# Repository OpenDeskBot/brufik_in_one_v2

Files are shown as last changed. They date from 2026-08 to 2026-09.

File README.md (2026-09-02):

# Brufik in One — 一个住在你桌面的硅基朋友

你好！这里有一个**硅基朋友**，你想认识一下吗？

他会睁大眼睛看着你说话，被夸奖时害羞脸红、眨眼睛，被吵醒时一脸迷糊；他记得你说过的话——知道你喜欢喝咖啡，下午 3 点会主动提醒你「该站起来活动啦」；你问他天气，他真的会去网上查，查完还得意地晃两下脑袋；你打断他说话，他会乖乖停下来听你说。

他不是视频里的 demo，而是**开源、可以亲手攒出来**的：3D 打印外壳 + ESP32 主控 + 一块小屏幕 + 两个舵机 + 一个喇叭，配上一套全开源的语音 AI 后台，百元级预算就能从零到「活」。

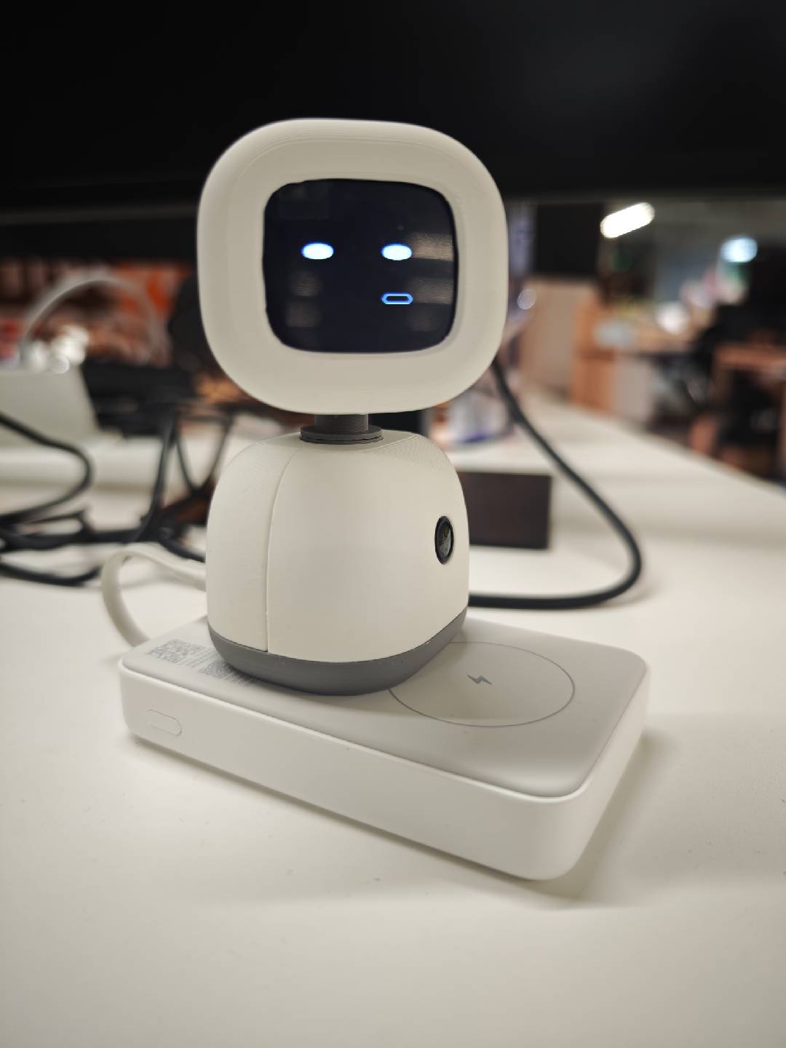
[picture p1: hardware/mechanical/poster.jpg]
Brufik 桌面机器人实物


---

## 为什么值得一试

- 🗣️ **开口即聊，无唤醒词**：插电上电，直接对它说话。VAD 自动起停，不用按键、不用喊「你好小歪」。
- 😊 **表情 + 音素级口型**：TTS 返回音素时间戳，屏幕上的嘴型逐帧对齐声音；语音、嘴型、底部屏显文字三路同步。
- 🎙️ **全双工音频（AEC）**：它说话时你可以直接打断——回声消除（ESP-SR AFE）让它「边听边说」，而不是死板地你一句我一句排队。
- ⚡ **随时打断**：高优先级消息（如闹钟、紧急提醒）通过 `pb_cancel` 抢占，立刻打断低优先级播放。
- 👀 **认人 + 追视**：认得的脸能叫出名字（MediaPipe 检测 + InsightFace 512 维档案），摄像头自动转头跟随。
- 🌐 **LLM 工具生态**：联网搜索、抓网页、拍照取景、登记人脸、读写文件沙箱……LLM 不只聊天，还能动手。
- 📦 **全栈开源**：STEP 结构件、PCB、自定义 bootloader、ESP32 固件、Python 后台、Web 控制台，一套仓库交付，可完整复刻。

---

## 它怎么「活」起来

设备端「轻」、后台端「重」：ESP32 只负责采音、播音、画屏、转舵机；所有智能（识别、对话、人脸、记忆、定时）都在后台。两者通过**一条 WebSocket 长连接**（`/asr_chat`）实时联动。

```
你说话 → 设备采集 PDM 麦克风（16kHz）
              │  audio 帧上行（Opus/PCM + flush）
              ▼
        服务端语音管线：VAD → ASR → LLM(工具) → TTS → 组帧
              │  pb_start / pb_chunk / pb_end + 24kHz PCM 下行
              ▼
        设备端回应：播音 + 嘴型 + 转头 + 屏显文字 + RGB 状态灯
```

> 详细协议见 [service/docs/esp32_pb_protocol.md](service/docs/esp32_pb_protocol.md)。

---

## 仓库结构

| 目录 | 角色 | 内容 |
|---|---|---|
| [`hardware/`](hardware/) | 实体机器人 | ESP32-S3 固件（FreeRTOS 多任务）、机械结构件（STEP/说明书）、PCB 设计文件（Gerber/BOM，V2.0 双板）、自定义 bootloader / 分区表、烧录脚本 |
| [`service/`](service/) | 大脑（后台） | deskbot-server 主服务（WS + Web 控制台）、VAD/ASR/LLM/TTS 语音管线、人脸识别、记忆与定时任务、协议文档 |

---

## 🔧 自己动手做一台

硬件全部开源：两块 **PCB V2.0**（主控 Base + 屏幕 LCM）+ 3D 打印结构件 + 通用小零件，按下面清单采购即可。详细组装步骤见 [图文说明书](hardware/mechanical/小歪v2.0组装说明书PDF.pdf)，接线表与烧录见 [hardware/README_zh.md](hardware/README_zh.md)。

### 购买材料清单（每套）

| 类别 | 品名 | 规格 | 每套用量 | 说明 |
|---|---|---|---|---|
| 硬件 | 屏幕 | 1.83英寸TFT液晶屏ST7789小屏240x284显示器LCD彩屏SPI圆角 | 1 | 12p插接 无触摸 |
| 硬件 | 摄像头 | ov3660异面120°广角40mm长 | 1 | — |
| 硬件 | 扬声器 | 2011腔体喇叭8欧1瓦 | 1 | 1.25插头 |
| 硬件 | 9g舵机 | 180°舵机 | 1 | JR2.54插口 |
| 硬件 | 3.7g舵机 | 长宽尺寸20.2*8.5mm | 1 | 1、工作电压必须满足5v；2、长宽20.2*8.5mm（允许±0.5mm公差，一般都是这种规格）；3、JR2.54插口 |
| 硬件 | FPC天线 | FPC天线 IPEX 1代接头 线长5cm 尺寸28*9mm | 1 | 尺寸越大信号越好，但是不得大于30*30mm |
| 硬件 | 屏幕PCB | 详见 PCB sheet | 1 | 即 **PCB V2.0 LCM** |
| 硬件 | 主控PCB | 详见 PCB sheet | 1 | 即 **PCB V2.0 Base** |
| 辅料 | M2*5自攻螺丝 | 十字盘头不锈钢平尾 | 14 | — |
| 辅料 | M2*8自攻螺丝 | 十字盘头不锈钢平尾 | 9 | — |
| 辅料 | M2*12自攻螺丝 | 十字盘头不锈钢平尾 | 2 | — |
| 辅料 | 连接线 | 1.25 6p 150mm 双头同向硅胶线 | 1 | 双头同向，见[示意图](hardware/mechanical/连接线_双向同头示意图.png) |

### PCB 与 3D 结构件

**主控 PCB（PCB V2.0 Base）**——ESP32-S3-WROOM-1U-N16R8 + 板载麦克风 / NS4168 功放 / TYPE-C： [Gerber](hardware/mechanical/小歪_Gerber_PCB_V2.0_Base_2026-09-02.zip) · [BOM](hardware/mechanical/BOM_V2.0_Base_PCB_V2.0_Base_2026-09-02.xlsx)

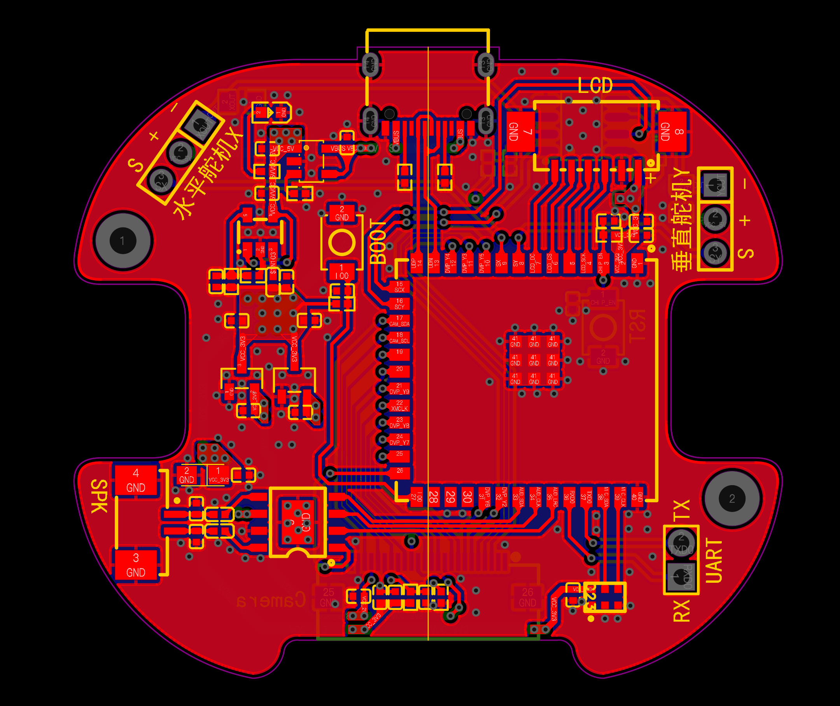
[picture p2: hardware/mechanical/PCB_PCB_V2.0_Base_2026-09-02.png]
PCB V2.0 Base 主控板


**屏幕 PCB（PCB V2.0 LCM）**——屏幕转接板，FPC 与主控相连： [BOM](hardware/mechanical/BOM_V2.0_LCM_PCB_V2.0_LCM_2026-09-02.xlsx)

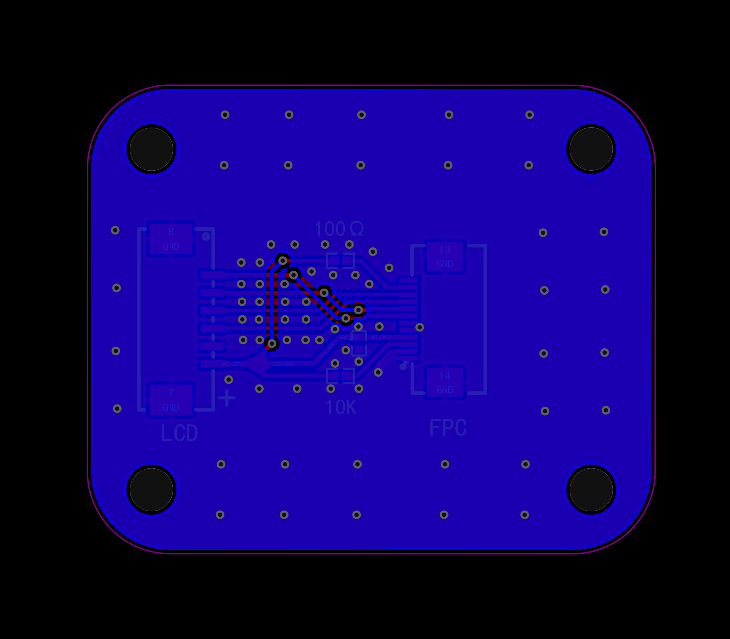
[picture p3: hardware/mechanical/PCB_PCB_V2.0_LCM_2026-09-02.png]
PCB V2.0 LCM 屏幕板


- **3D 打印件（STEP）：** [`小歪机器人v2.0打印件stp.stp`](hardware/mechanical/小歪机器人v2.0打印件stp.stp)
- **摄像头卡子（OV3660 固定）：** [`小歪机器人v2.0 ov3660摄像头卡子.stp`](<hardware/mechanical/小歪机器人v2.0 ov3660摄像头卡子.stp>)

---

## 快速开始

### 🧪 方式 A：没有硬件，5 分钟跑通语音对话

只需一台带 Python 的电脑（Ubuntu 22.04/24.04、macOS 或 Windows Git Bash），用模拟客户端代替机器人，把整条语音管线跑起来：

```bash
# 1. 安装系统依赖（Ubuntu；macOS 用 brew install ffmpeg python@3.11）
sudo apt install -y python3.11 python3.11-venv python3.11-dev ffmpeg curl git

# 2. 准备配置（默认全部免费本地模型，无需任何云 Key；用云端模型时再在 .env 配置）
cd service
cp .env.example .env

# 3. 一键启动（自动建 venv、下载 VAD 模型，拉起主服务 + Web 控制台）
chmod +x start.sh
./start.sh
```

首次启动只自动下载 Silero VAD 模型（约 2.3MB，语音切句用）。ASR / 本地 LLM / TTS / 声纹等模型均已迁至**独立外部服务**，由各自 `install.sh` 自备独立 venv 与模型副本：启动后到控制台「外部服务」（高级 → 外部服务）安装并启动所需服务（funasr 9102 / moss-tts-nano 9101 等），详见 [service/docs/external_services.md](service/docs/external_services.md)。启动后：

| 服务 | 地址 |
|---|---|
| Web 控制台 | `http://<本机IP>:9000/` |
| 设备 WebSocket | `ws://<本机IP>:9000/asr_chat?device_id=<设备ID>` |

另开一个终端，用模拟客户端发一段 16kHz 单声道 WAV，体验「识别 → LLM → TTS → pb 下行」全流程：

```bash
source .venv/bin/activate
python tools/test_client.py \
  --ws-url "ws://127.0.0.1:9000/asr_chat?device_id=deskbot_dev" \
  --input-wav demo_16k_mono.wav
```

> WAV 须为 **16 kHz / mono / s16le**。没有现成 WAV？可以用麦克风现场录一段：
>
> ```bash
> # macOS：avfoundation；Linux：alsa
> ffmpeg -f avfoundation -i ":0" -ar 16000 -ac 1 -c:a pcm_s16le demo_16k_mono.wav
> ```
>
> 嫌麻烦可以直接用麦克风实时对话：`python tools/live_mic_client.py --ws-url "ws://127.0.0.1:9000/asr_chat?device_id=deskbot_dev"`（详见 [tools/README.md](service/tools/README.md)）。

### 🤖 方式 B：完整部署（后台 + 真机）

**后台**与方式 A 完全相同；之后烧录固件：

```bash
cd hardware
# 1. 编辑 firmware/deskbot_config.h：WiFi（WIFI_DEFAULT_SSID/PASSWORD）与
#    DESKBOT_WS_HOST / DESKBOT_WS_PORT（指向你的后台）
# 2. 烧录 + 串口监视（需 PlatformIO，Python ≥3.10）
./flash_rom.sh all
```

上电后机器人自动连 WiFi 并显示状态；连不上时自动开开放热点（SSID = 设备 ID），浏览器打开 `http://192.168.4.1/` 网页配网。

设备 ID 由芯片 MAC 生成（如 `deskbot_e83dc1faea30`），设备链路**只需 device_id，不需要 API Key**——把同一 ID 在控制台「我的设备」里绑定到你的账号，即可管理它的记忆、定时任务与人脸档案。

---

## 和它玩什么

| 玩法 | 说明 |
|---|---|
| 🗣️ 自然对话 | 多轮上下文（10 分钟会话），人设「小歪」，情绪丰富、会害羞会傲娇 |
| 📅 定时提醒 | 说「提醒我 3 点喝水」，LLM 调用 `schedule_task`，到点主动播报（北京时区 cron） |
| 🧠 记住你 | 说「我叫小明，喜欢喝咖啡」，`memory_add` 写入长期记忆，跨会话生效 |
| 😊 情绪表达 | 被夸奖会害羞眨眼，被凶会委屈炸毛；表情、转头、语音联动 |
| 👁️ 认人 + 跟随 | `register_face` 登记人脸，之后能叫名字；摄像头自动追脸转头 |
| 🌐 联网 | 「帮我查一下明天的天气」——`webfetch` / `websearch` 后回答 |
| 📝 屏显文字 | 语音之外，它还可以在屏幕上用彩色文字「写」给你看 |
| 🛠️ 调试台 | 控制台里不经过设备直接试 LLM、试 TTS、跑整轮模拟 |

---

## 技术速览（与代码一致）

### 语音管线（`service/config.yaml` 可调）

**免费本地优先**：VAD / ASR / LLM / TTS 默认全部在本机运行，零 API 费用；云端收费模型可在 `service/config.yaml` 或控制台「机器人设置」按需切换。

| 环节 | 实现 | 说明 |
|---|---|---|
| VAD | Silero VAD（ONNX，本地） | 端点检测，自动起停 |
| ASR | FunASR · SenseVoiceSmall（本地 ONNX） | 中文，16kHz，支持 Opus/PCM |
| LLM | **本地优先**：Qwen3.8-2B（llama-server，端口 9106）或 MiniCPM5-1B（端口 9105），OpenAI 兼容协议；可切换云端火山方舟（DeepSeek 等）/ OpenAI / DashScope | 多轮工具循环，JSON 输出 |
| TTS | **本地优先**：MOSS-TTS-Nano；可切换云端豆包 Doubao | 返回音素时间戳，驱动屏幕口型 |
| 组帧 | pb wire：音频 + 动画 + 舵机 + 屏字 | 24kHz s16le PCM，优先级队列（0 空闲/1 说话/2 紧急/3 调试） |

### 设备 WebSocket 协议

单条持久连接，上行、下行均采用 **「JSON + 紧随一条 binary」**（长度由 `next_bin_len` 声明，不用 base64）：

- **上行**：`audio`（+flush 触发识别）、`camera_frame`（可选 JPEG）、`pb_ack`（播放背压）、`ping`
- **下行**：`pb_start` / `pb_chunk` / `pb_end` / `pb_single` + 24kHz PCM；`pb_cancel` 支持抢占打断

### LLM 工具（`llm_tool_runner.py` / `web_tools.py`）

`schedule_task`（定时提醒）· `memory_add` / `memory_del`（长期记忆）· `get_camera`（取画面）· `register_face`（登记人脸）· `set_camera_follow`（人脸跟随）· `webfetch` / `websearch`（联网）· 沙箱文件读写 · `interim_tts`（边说边想）

### 固件要点（`hardware/firmware/`）

- 主控 **ESP32-S3**（当前固件适配自研 Deskbot v2 板，由 Seeed XIAO ESP32S3 Sense 方案移植）
- 外设：ST7789P 240×284 SPI 屏 · 双轴舵机（X 左右 GPIO16 / Y 上下 GPIO15）· PDM 麦克风 · NS4168 I2S 功放 · OV2640/OV3660 120° 广角摄像头（esp_camera 自动识别）· RGB 状态灯
- **ESP-SR AFE**（AEC 回声消除 / NS 降噪 / AGC / VAD）→ 全双工音频，可打断
- 自定义 bootloader 钩子，避免上电/烧录时舵机误触发抽动
- 工具链：pioarduino 55.03.39 · Arduino-ESP32 3.3.9 + ESP-IDF 5.5.4 · Python ≥3.10

### 数据与隔离

SQLite（`opendesk.db`）存用户、设备绑定、定时任务；记忆、会话、人脸档案按设备目录隔离（`data/<device_id>/`）。本地调试工具的 Web / HTTP / 调试订阅可用免费体验 Key（`data/.free_api_key`，详见 [service/README.md](service/README.md)）。

---

## 文档索引

| 文档 | 内容 |
|---|---|
| [service/README.md](service/README.md) | 后台部署、使用手册、与 ESP32 交互概要 |
| [service/docs/esp32_pb_protocol.md](service/docs/esp32_pb_protocol.md) | ESP32 通信、鉴权、pb 协议 |
| [service/docs/SERVER.md](service/docs/SERVER.md) | 主服务 API、配置、LLM 工具 |
| [service/docs/api_interfaces.md](service/docs/api_interfaces.md) | Web 控制台与设备服务接口清单 |
| [service/docs/ARCHITECTURE.md](service/docs/ARCHITECTURE.md) | 后台代码分层与模块 |
| [service/tools/README.md](service/tools/README.md) | 本地联调脚本（模拟客户端 / 麦克风实时测试） |
| [hardware/README_zh.md](hardware/README_zh.md) | 固件烧录、元器件采购清单、组装与接线说明 |

## 许可证

- **硬件设计**（[`hardware/mechanical/`](hardware/mechanical/)）：CERN-OHL-S-2.0
- **固件**（[`hardware/firmware/`](hardware/firmware/)）：GPL-3.0
- **后台**（[`service/`](service/)）：GPL-3.0

各子目录内有对应 `LICENSE` 文件。

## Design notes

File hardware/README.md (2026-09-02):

# Brufik

[中文](README_zh.md) | English

**Hardware in this repository is under [CERN-OHL-S-2.0](mechanical/LICENSE); software is under [GPL-3.0](firmware/LICENSE).**

**Brufik** is an open-source deskbot built on a custom **Deskbot v2 mainboard** (ESP32-S3-WROOM-1U-N16R8). Backend lives in this monorepo: [`../service/`](../service/).

Brufik deskbot — assembled unit

---

## Toolchain

| Item | Value |
|---|---|
| Board | Custom **Deskbot v2 mainboard** (PCB V2.0 Base, ESP32-S3-WROOM-1U-N16R8) |
| Platform | [pioarduino](https://github.com/pioarduino/platform-espressif32) **55.03.39** (do **not** use stock PlatformIO `espressif32` Arduino 2.0.17 / IDF 4.4.7) |
| Framework | Arduino-ESP32 **3.3.9** + ESP-IDF **5.5.4** |
| Host Python | **≥3.10** (recommend `python3.11 -m venv hardware/.venv` then `pip install platformio`) |
| Flash | [`./flash_rom.sh`](flash_rom.sh) (prefers `.venv/bin/pio`; ports include `/dev/tty.usbmodem*`) |

Audio uses Arduino **`ESP_I2S`** (PDM RX mic + STD TX amp). Camera uplink prefers hardware JPEG, else RGB565 + `frame2jpg` (AWB warmup frames after init). `device_id` comes from `esp_read_mac` (`deskbot_<mac>`).

---

## 1. Out of the box

1. Edit [`firmware/deskbot_config.h`](firmware/deskbot_config.h): set `WIFI_DEFAULT_*` to your AP (or set the AP to match those macros), and set `DESKBOT_WS_HOST` / `DESKBOT_WS_PORT` to your backend.
2. Power on — the device joins WiFi and opens `ws://…/asr_chat?device_id=…` (**device_id only**; no API key or PIN on the device link).
3. To change WiFi later: power on, join the open soft-AP whose SSID is the **`device_id`** (e.g. `deskbot_e83dc1faea30`), then open the URL on the screen (usually **`http://192.168.4.1/`**).

---

## 2. Developers

```bash
# from hardware/
./flash_rom.sh all          # build + upload + monitor
./flash_rom.sh build
./flash_rom.sh upload [port]
./flash_rom.sh log [port]
```

Backend: [`../service/`](../service/). Firmware WebSocket: **`/asr_chat`**. Camera frames go over the same WS (`camera_frame`); there is **no** always-on local camera HTTP page after STA is up (provisioning portal only during AP mode). Debug JPEG preview is on the server: `/camera_view`.

WiFi write-timeout patches (Arduino 3.x) target `NetworkClient.cpp` (fallback `WiFiClient.cpp`); see `scripts/`.

---

## 3. DIY assembly

| Part | Notes | Search terms |
|---|---|---|
| Main PCB | **PCB V2.0 Base** — custom mainboard: ESP32-S3-WROOM-1U-N16R8, **onboard mic** + NS4168 amp + USB-C. [BOM](mechanical/BOM_V2.0_Base_PCB_V2.0_Base_2026-09-02.xlsx), [Gerber](mechanical/小歪_Gerber_PCB_V2.0_Base_2026-09-02.zip) in repo | JLC |
| LCD PCB | **PCB V2.0 LCM** — screen carrier board, FPC to mainboard. [BOM](mechanical/BOM_V2.0_LCM_PCB_V2.0_LCM_2026-09-02.xlsx) in repo | JLC |
| Camera | **OV3660**, **off-axis**, **120°** wide, **40 mm** long. Firmware `esp_camera` auto-detects the sensor; OV2640/OV3660 share the pinout | `OV3660 camera off-axis 120° 40mm` |
| LCD | 1.83" SPI **ST7789** 240×284, rounded corners, 12-pin socket, no touch | Waveshare 1.83 LCD Rev2 |
| Servos | **Large + small**: **9g (tilt) + 3.7g (pan)**, both **JR2.54**; 3.7g needs **5V**, 20.2×8.5 mm (±0.5 mm) | `SG90` / `9g servo`, `3.7g micro servo` |
| Amp | I2S (onboard NS4168) | — |
| Speaker | **2011** type, 8Ω 1W, 1.25 plug | `2011 speaker`, `8Ω 2011` |
| FPC antenna | IPEX 1st-gen connector, 5 cm cable, 28×9 mm (≤30×30 mm) | `FPC antenna IPEX 1 5cm` |
| Power | **5V ≥1A** for servos; USB-C on mainboard | — |

### BOM for ordering (per kit)

| Category | Item | Spec | Qty | Notes |
|---|---|---|-----|---|
| Hardware | Screen | 1.83" TFT LCD ST7789 240×284 SPI rounded corners | 1 | 12-pin socket, no touch |
| Hardware | Camera | OV3660 off-axis 120° wide-angle, 40 mm long | 1 | — |
| Hardware | Speaker | 2011 chamber, 8Ω 1W | 1 | 1.25 plug |
| Hardware | 9g servo | 180° servo | 1 | JR2.54 socket |
| Hardware | 3.7g servo | 20.2 × 8.5 mm | 1 | 1) Must run on **5V**; 2) 20.2×8.5 mm (±0.5 mm tolerance, standard size); 3) JR2.54 socket |
| Hardware | FPC antenna | IPEX gen-1 connector, 5 cm cable, 28×9 mm | 1 | Larger gives better signal, but ≤ 30×30 mm |
| Hardware | LCD PCB | See PCB sheet | 1 | i.e. **PCB V2.0 LCM** |
| Hardware | Main PCB | See PCB sheet | 1 | i.e. **PCB V2.0 Base** |
| Fasteners | M2×5 self-tapping screw | Cross pan-head, stainless, flat tip | 14 | — |
| Fasteners | M2×8 self-tapping screw | Cross pan-head, stainless, flat tip | 9 | — |
| Fasteners | M2×12 self-tapping screw | Cross pan-head, stainless, flat tip | 2 | — |
| Fasteners | Cable | 1.25 6-pin 150 mm, dual-head same-direction silicone | 1 | Same-direction, see [diagram](mechanical/连接线_双向同头示意图.png) |

### Assembly guide & reference photos

- **Step-by-step manual:** [`mechanical/小歪v2.0组装说明书PDF.pdf`](mechanical/小歪v2.0组装说明书PDF.pdf)
- **3D-printed parts (STEP):** [`mechanical/小歪机器人v2.0打印件stp.stp`](mechanical/小歪机器人v2.0打印件stp.stp)
- **Camera clip (OV3660 mount):** [`mechanical/小歪机器人v2.0 ov3660摄像头卡子.stp`](<mechanical/小歪机器人v2.0 ov3660摄像头卡子.stp>)

**Main PCB (PCB V2.0 Base):**

PCB V2.0 Base mainboard

**LCD PCB (PCB V2.0 LCM):**

PCB V2.0 LCM screen board

### Wiring (PCB V2.0, silkscreen = GPIO numbers)

> The v2.0 mainboard silk labels **GPIO numbers** directly; on old XIAO drawings, IO8 / IO3 mean GPIO, not pads D8 / D3.

| Device | Signals | GPIO | Notes |
|---|---|---|---|
| LCD SPI | MOSI/SCK/CS/DC | **GPIO5 / 4 / 6 / 7** | RST/BL tied to 3.3V |
| Servo X (pan) | PWM | **GPIO16** | 3.7g small; avoids USB 19/20 & strapping pins |
| Servo Y (tilt) | PWM | **GPIO15** | 9g large |
| Amp NS4168 | DIN/BCLK/LRC | **GPIO40 / 41 / 42** | I2S → 2011 speaker; SD=GPIO45 enable-high |
| Mic | PDM CLK/DATA | **GPIO1 / GPIO2** | Onboard (LinkMems LMD2718T271) |
| Servo power | 5V / GND | Separate 5V ≥1A | Common ground with logic |

Pin macros: [`firmware/deskbot_config.h`](firmware/deskbot_config.h); camera 8-bit parallel + SCCB pins: [`firmware/camera.cpp`](firmware/camera.cpp).

---

## License

| Scope | License | File |
|---|---|---|
| Hardware ([`mechanical/`](mechanical/)) | CERN-OHL-S-2.0 | [`mechanical/LICENSE`](mechanical/LICENSE) |
| Software ([`firmware/`](firmware/) etc.) | GNU GPL v3.0 | [`firmware/LICENSE`](firmware/LICENSE) |

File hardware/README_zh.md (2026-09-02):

# Brufik

[English](README.md)

**本仓库中的硬件设计部分遵循 [CERN-OHL-S-2.0](mechanical/LICENSE)，软件部分遵循 [GPL-3.0](firmware/LICENSE)。**

**Brufik** 是一款开源桌面机器人：自研 **Deskbot v2 主控板**（ESP32-S3-WROOM-1U-N16R8）+ 屏 + 舵机 + 麦 + 喇叭。语音与画面走本 monorepo 后台 [`../service/`](../service/)。

Brufik 桌面机器人 — 组装完成实物

---

## 工具链

| 项 | 说明 |
|---|---|
| 板型 | 自研 **Deskbot v2 主控板**（PCB V2.0 Base，ESP32-S3-WROOM-1U-N16R8） |
| Platform | [pioarduino](https://github.com/pioarduino/platform-espressif32) **55.03.39**（**不要**用官方 PlatformIO `espressif32` 的 Arduino 2.0.17 / IDF 4.4.7） |
| 框架 | Arduino-ESP32 **3.3.9** + ESP-IDF **5.5.4** |
| 宿主机 Python | **≥3.10**（推荐 `cd hardware && python3.11 -m venv .venv && .venv/bin/pip install platformio`） |
| 烧录 | [`./flash_rom.sh`](flash_rom.sh)（优先 `.venv/bin/pio`；串口含 `/dev/tty.usbmodem*`） |

音频走 Arduino **`ESP_I2S`**（PDM 收音 + STD 功放）。相机优先硬件 JPEG，否则 RGB565 + `frame2jpg`（init 后丢弃若干帧做 AWB）。`device_id` 由 `esp_read_mac` 生成（`deskbot_<mac>`）。

---

## 一、开箱即用

1. 编辑 [`firmware/deskbot_config.h`](firmware/deskbot_config.h)：把 `WIFI_DEFAULT_*` 改成你家路由，或把热点改成与宏一致；并设置 `DESKBOT_WS_HOST` / `DESKBOT_WS_PORT`。
2. 上电后连 WiFi，并连接 `ws://…/asr_chat?device_id=…`（**设备链路仅需 device_id，无 API Key / PIN**）。
3. 改家里 WiFi：上电后连接开放热点，SSID 为 **`device_id`**（如 `deskbot_e83dc1faea30`），浏览器打开屏幕地址（通常 **`http://192.168.4.1/`**）按 onboarding 保存。

---

## 二、本地开发者

**需要：** USB、PlatformIO（Python ≥3.10）、串口权限（Linux `dialout`）。

```bash
# 在 monorepo 的 hardware/ 目录
./flash_rom.sh all          # 编译 + 烧录 + 监视
./flash_rom.sh build
./flash_rom.sh upload [端口]
./flash_rom.sh log [端口]
```

| 命令 | 说明 |
|---|---|
| `./flash_rom.sh build` | 编译 |
| `./flash_rom.sh upload [端口]` | 烧录 |
| `./flash_rom.sh log [端口]` | 串口监视 |
| `./flash_rom.sh all [端口]` | 烧录 + 监视 |

后台见 [`../service/`](../service/)。固件 WebSocket：**`/asr_chat`**。摄像头 JPEG 经同一 WS 上行（`camera_frame`）；STA 正常运行后**没有**常驻本机摄像头网页（仅配网 AP 门户）。服务端调试预览：`/camera_view`。

Arduino 3.x 的 WiFi write timeout 补丁优先改 `NetworkClient.cpp`（见 `scripts/`）。

---

## 三、自行组装

### 元器件与采购关键词

| 部件 | 说明 | 搜索关键词（淘宝/嘉立创等） |
|---|---|---|
| 主控 PCB | **PCB V2.0 Base** 自研主控板：ESP32-S3-WROOM-1U-N16R8 + **板载麦克风** + 功放（NS4168）+ TYPE-C；[BOM](mechanical/BOM_V2.0_Base_PCB_V2.0_Base_2026-09-02.xlsx)、[Gerber](mechanical/小歪_Gerber_PCB_V2.0_Base_2026-09-02.zip) 见仓库 | 嘉立创下单 |
| 屏幕 PCB | **PCB V2.0 LCM** 屏幕转接板，FPC 与主控相连；[BOM](mechanical/BOM_V2.0_LCM_PCB_V2.0_LCM_2026-09-02.xlsx) 见仓库 | 嘉立创下单 |
| 摄像头 | **OV3660**；**异面**（非同面）；广角 **120°**；**40 mm** 长。固件 esp_camera 上电自动识别传感器，OV2640 / OV3660 引脚通用 | `OV3660 摄像头模组`、`ov3660 异面 120度 40mm` |
| 屏幕 | 1.83 寸 SPI，**ST7789** 240×284，圆角，12p 插接、无触摸 | `微雪 1.83寸 LCD`、`Waveshare 1.83 LCD Rev2`、`ST7789 240x284` |
| 舵机 | 一大一小：**9g（俯仰）+ 3.7g（水平）**，均 **JR2.54 插口**；3.7g 工作电压需 **5V**，尺寸 20.2×8.5mm（±0.5mm） | `SG90` / `9g 舵机`；`3.7g 舵机 微型` |
| 喇叭 | **2011** 腔体喇叭，8Ω 1W，1.25 插头 | `喇叭 2011`、`8Ω 2011 扬声器` |
| FPC 天线 | IPEX 1 代接头，线长 5cm，尺寸 28×9mm（≤30×30mm） | `FPC天线 IPEX 1代 5cm` |
| 电源 | **5V ≥1A** 给舵机；主控板 TYPE-C 供电 | `5V 1A 电源`、`USB 5V` |

### 购买材料清单（每套）

| 类别 | 品名 | 规格 | 每套用量 | 说明 |
|---|---|---|---|---|
| 硬件 | 屏幕 | 1.83英寸TFT液晶屏ST7789小屏240x284显示器LCD彩屏SPI圆角 | 1 | 12p插接 无触摸 |
| 硬件 | 摄像头 | ov3660异面120°广角40mm长 | 1 | — |
| 硬件 | 扬声器 | 2011腔体喇叭8欧1瓦 | 1 | 1.25插头 |
| 硬件 | 9g舵机 | 180°舵机 | 1 | JR2.54插口 |
| 硬件 | 3.7g舵机 | 长宽尺寸20.2*8.5mm | 1 | 1、工作电压必须满足5v；2、长宽20.2*8.5mm（允许±0.5mm公差，一般都是这种规格）；3、JR2.54插口 |
| 硬件 | FPC天线 | FPC天线 IPEX 1代接头 线长5cm 尺寸28*9mm | 1 | 尺寸越大信号越好，但是不得大于30*30mm |
| 硬件 | 屏幕PCB | 详见 PCB sheet | 1 | 即 **PCB V2.0 LCM** |
| 硬件 | 主控PCB | 详见 PCB sheet | 1 | 即 **PCB V2.0 Base** |
| 辅料 | M2*5自攻螺丝 | 十字盘头不锈钢平尾 | 14 | — |
| 辅料 | M2*8自攻螺丝 | 十字盘头不锈钢平尾 | 9 | — |
| 辅料 | M2*12自攻螺丝 | 十字盘头不锈钢平尾 | 2 | — |
| 辅料 | 连接线 | 1.25 6p 150mm 双头同向硅胶线 | 1 | 双头同向，见[示意图](mechanical/连接线_双向同头示意图.png) |

### 组装说明与参考图

- **图文说明书：** [`mechanical/小歪v2.0组装说明书PDF.pdf`](mechanical/小歪v2.0组装说明书PDF.pdf)
- **3D 打印件（整机 STP）：** [`mechanical/小歪机器人v2.0打印件stp.stp`](mechanical/小歪机器人v2.0打印件stp.stp)
- **摄像头卡子（OV3660 固定用）：** [`mechanical/小歪机器人v2.0 ov3660摄像头卡子.stp`](<mechanical/小歪机器人v2.0 ov3660摄像头卡子.stp>)

**主控 PCB（PCB V2.0 Base）：**

PCB V2.0 Base 主控板

**屏幕 PCB（PCB V2.0 LCM）：**

PCB V2.0 LCM 屏幕板

### 接线（PCB V2.0 主控板，丝印即 GPIO 号）

> v2.0 主控板丝印直接标 **GPIO 号**；旧 XIAO 图纸上的 IO8 / IO3 指 GPIO，不是丝印 D8 / D3。

| 外设 | 信号 | GPIO | 备注 |
|---|---|---|---|
| **LCD** | MOSI / SCK / CS / DC | **GPIO5 / 4 / 6 / 7** | SPI；RST/BL 硬接 3.3V |
| **舵机 左右 (X)** | PWM | **GPIO16** | 3.7g 小舵机；避开 USB 19/20 与 strapping 引脚 |
| **舵机 上下 (Y)** | PWM | **GPIO15** | 9g 大舵机 |
| **功放 NS4168** | DIN / BCLK / LRC | **GPIO40 / 41 / 42** | I2S → 2011 喇叭；SD=GPIO45 高电平使能 |
| **麦克风** | PDM CLK / DATA | **GPIO1 / GPIO2** | 主控板板载（聆麦 LMD2718T271） |
| **舵机电源** | 5V / GND | 独立 5V≥1A | 与逻辑共地 |

引脚宏见 [`firmware/deskbot_config.h`](firmware/deskbot_config.h)；摄像头 8-bit 并口 + SCCB 引脚见 [`firmware/camera.cpp`](firmware/camera.cpp)。

---

## 许可证

| 范围 | 协议 | 文件 |
|---|---|---|
| 硬件设计（[`mechanical/`](mechanical/)） | CERN-OHL-S-2.0 | [`mechanical/LICENSE`](mechanical/LICENSE) |
| 软件（[`firmware/`](firmware/) 等） | GNU GPL v3.0 | [`firmware/LICENSE`](firmware/LICENSE) |

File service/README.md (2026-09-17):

# deskbot-server

ESP32 桌面机器人后端：设备上传语音（可选摄像头），服务端完成 **VAD → ASR → LLM → TTS**，经 **pb** 协议下发 PCM、屏幕动画与舵机指令。

本目录位于 monorepo [`brufik_in_one/service/`](../)。固件见 [`../hardware/`](../hardware/)。

**License:** [GPL-3.0](LICENSE)

---

## 最快部署（3 步）

**环境：** Ubuntu 22.04 / 24.04（或 macOS / Windows Git Bash）、Python **3.11**、`ffmpeg`、可访问外网（首次下载模型与 pip 包）。

```bash
# 1. 系统依赖（Ubuntu）
sudo apt update
sudo apt install -y python3.11 python3.11-venv python3.11-dev ffmpeg curl git

# 2. 配置大模型 Key（必填）
cd service   # monorepo 内；独立 clone 时进入对应目录
cp .env.example .env
# 编辑 .env，填写 SILICONFLOW_API_KEY（硅基流动，系统默认大脑；免费额度足够日常对话）
# 可选：ARK_API_KEY 与 ARK_MODEL（火山方舟，仅当设备在「机器人配置 → 大脑 LLM」中选 ark 时需要）

# 3. 一键启动（自动建 venv、下载 VAD 模型、起主服务 + Web 控制台）
chmod +x start.sh
./start.sh
```

主服务本身只下载 Silero VAD 模型（约 2.3MB，语音切句用）；**ASR / TTS / 声纹 / 本地 LLM 模型均由各独立外部服务安装时自备**（独立 venv + 服务目录内模型，不再进主服务）——启动后在控制台菜单「外部服务」（高级 → 外部服务）安装并启动所需服务即可，详见 [docs/external_services.md](docs/external_services.md)。

**第二次及以后**若 `.venv` 已完整，直接 `./start.sh` 会自动跳过 pip 安装；也可显式：

```bash
SKIP_SETUP=1 ./start.sh
# 或
FAST_START=1 ./start.sh
```

| 服务 | 地址 | 用途 |
|---|---|---|
| **Web 控制台** | `http://<本机IP>:9000/` | 注册登录、设备绑定、定时任务、记忆等 |
| **设备 WebSocket** | `ws://<本机IP>:9000/asr_chat?device_id=<id>` | ESP32 语音对话主链路（仅需 `device_id`，无 API Key / PIN） |

Web / HTTP 接口与调试订阅使用**控制台登录会话**；调试 WebSocket（`/camera_view`、`/device_pipeline` 订阅侧）在「调试台」页面签发 `debug_token`。本地联调脚本可读取 `data/.free_api_key`（若存在）。

---

## 快速使用

### 1. 打开控制台

浏览器访问 `http://<本机IP>:9000/` → **注册**账号 → 登录进入工作台。

### 2. 鉴权方式（Web / HTTP / 调试订阅）

控制台注册登录后，Web / HTTP 接口直接走会话；调试 WebSocket 订阅（`/camera_view`、`/device_pipeline`）在「调试台」页面获取 `debug_token`。设备固件**不需要**任何 Key。

### 3. 绑定设备

**我的设备** 中添加 `device_id`（与固件一致，如 `deskbot_e83dc1faea30`）即可绑定。后续管理定时任务、记忆、人脸档案时需先**选择设备**。

### 4. 连接设备对话

固件连接（与 `hardware/firmware` 一致）：

```
ws://<本机IP>:9000/asr_chat?device_id=<你的device_id>
```

说话后发送 `flush`，服务端识别 → 调用 LLM → TTS → pb 下行播放。

### 5. 无硬件时本地试跑

```bash
source .venv/bin/activate
python tools/test_client.py \
  --ws-url "ws://127.0.0.1:9000/asr_chat?device_id=deskbot_dev" \
  --input-wav demo_16k_mono.wav
```

WAV 须 **16 kHz / mono / s16le**。麦克风实时测试见 [tools/README.md](tools/README.md)。

### 6. 控制台常用功能

| 菜单 | 说明 |
|---|---|
| 工作台 | 用量概览与快捷入口 |
| 我的设备 | 绑定 / 切换 `device_id` |
| 定时任务 | 查看 LLM 创建的 cron 任务（北京时间），可删除 |
| 记忆 | 按设备管理长期记忆（注入 LLM） |
| 人脸识别 | 按设备查看人脸档案 |
| 用量看板 | 按 Key / 设备查看 ASR、人脸、LLM、TTS 字节统计 |
| 调试台 | 设备在线、LLM 试聊、豆包 TTS、流水线等 |

语音对话中，LLM 可通过工具创建定时提醒（`schedule_task`）、读写设备临时文件、联网搜索等，详见 [docs/SERVER.md](docs/SERVER.md)。

---

## 与 ESP32 的交互（概要）

单条 WebSocket：`/asr_chat?device_id=<id>`。上行、下行均采用 **「JSON + 紧随一条 binary」**，长度由 **`next_bin_len`** 声明，**不用 base64**。

```
┌──────── ESP32 ────────┐                    ┌──── deskbot-server ────┐
│ 麦克风 Opus/PCM       │  audio + binary    │ VAD → 外部 funasr 服务（HTTP）→ 文本     │
│ 可选 JPEG             │  camera_frame      │ → 方舟 LLM + tools │
│ flush / pb_ack        │ ─────────────────► │ → 豆包 TTS + 音素口型   │
│                       │                    │ → 组 pb + PCM           │
│ 播放 PCM + 画屏       │  pb_* + binary     │                         │
│ 舵机 / 音量 / 帧率    │ ◄───────────────── │                         │
└───────────────────────┘                    └─────────────────────────┘
```

TTS 默认使用独立进程 MOSS-TTS-Nano（`tts.provider: moss-tts-nano`，需先在「独立服务管理」安装启动 moss-tts-nano）；也可切换火山引擎豆包（`doubao`），凭证配置见 `.env` 与调试台「TTS 调试」。

### 上行（设备 → 服务端）

| JSON `type` | binary | 说明 |
|---|---|---|
| `audio` + `next_bin_len` | Opus 或 PCM | 语音流；段结束发 `flush` 触发识别与回复 |
| `camera_frame` + `next_bin_len` | JPEG | 可选；人脸检测与调试预览 |
| `pb_ack` | 无 | 播放缓冲回压 |
| `ping` | 无 | 保活 |

### 下行（服务端 → 设备）

默认 **`asr_chat_device_pb_only: true`**：只处理 **`pb_start` / `pb_chunk` / `pb_end` / `pb_single`**，以及紧随的 **s16le PCM**（24 kHz mono）。

完整字段见 **[docs/esp32_pb_protocol.md](docs/esp32_pb_protocol.md)**。

### 固件要点

1. URL 须带稳定 **`device_id`**（设备链路仅此一项鉴权，无需 API Key / PIN）。
2. JSON 与 binary **严格成对、顺序发送**。
3. 周期性 **`pb_ack`** 做播放回压。
4. 固件栈：Arduino-ESP32 **3.3.9** / IDF **5.5.4**（pioarduino），详见 [`../hardware/README.md`](../hardware/README.md)。

---

## 数据与目录

| 路径 | 说明 |
|---|---|
| `data/opendesk.db` | 用户、设备绑定、定时任务（SQLite） |
| `data/.free_api_key` | 免费体验 Key（勿提交 Git；本地联调脚本可读取） |
| `data/{device_id}/` | 按设备隔离的配置、session、记忆等（**不入 Git**） |
| `data/global/` | 全局共享配置（LLM 人设模板 `llm_system.txt` 等） |

---

## 文档索引

| 文档 | 内容 |
|---|---|
| [docs/api_interfaces.md](docs/api_interfaces.md) | Web 控制台与 deskbot 设备服务接口清单 |
| [docs/esp32_pb_protocol.md](docs/esp32_pb_protocol.md) | ESP32 通信、鉴权、pb 协议 |
| [docs/SERVER.md](docs/SERVER.md) | 主服务 API、配置、LLM 工具 |
| [docs/ARCHITECTURE.md](docs/ARCHITECTURE.md) | 代码分层与模块 |
| [tools/README.md](tools/README.md) | 本地联调脚本 |
| [docs/README.md](docs/README.md) | 文档目录 |

[CONTRIBUTING.md](CONTRIBUTING.md) · [SECURITY.md](SECURITY.md)

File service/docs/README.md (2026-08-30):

# 文档目录

本仓库文档与当前实现对齐，入口为根目录 [README.md](../README.md)。固件工具链见 [../../hardware/README.md](../../hardware/README.md)（Arduino-ESP32 3.3.9 / IDF 5.5.4 / pioarduino）。

## 协议与设备

| 文档 | 内容 |
|---|---|
| [api_interfaces.md](./api_interfaces.md) | Web 控制台与 deskbot 设备服务接口清单 |
| [esp32_pb_protocol.md](./esp32_pb_protocol.md) | ESP32 WebSocket 鉴权、上行 / 下行、pb v2 图元与表情 |

## 服务

| 文档 | 内容 |
|---|---|
| [SERVER.md](./SERVER.md) | 主服务：端口、控制台、LLM 工具、豆包 TTS 配置 |
| [ARCHITECTURE.md](./ARCHITECTURE.md) | 代码分层、对话与定时任务链路 |
| [external_services.md](./external_services.md) | 外部进程服务管理（manifest 契约 / 状态机 / 管理后台） |
| [external_service_design.md](./external_service_design.md) | 外部服务设计模式与后台交互规范（insightface-engine 为例，含新增服务清单与踩坑记录） |

## 联调工具

| 文档 | 内容 |
|---|---|
| [../tools/README.md](../tools/README.md) | WAV / 麦克风 / 相机测试客户端 |

## 协作与安全

| 文档 | 内容 |
|---|---|
| [../CONTRIBUTING.md](../CONTRIBUTING.md) | 贡献流程与测试 |
| [../SECURITY.md](../SECURITY.md) | 密钥、鉴权与部署安全 |

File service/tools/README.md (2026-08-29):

# 本地调试工具

在 `.venv` 激活后运行。

- **模拟设备主链路**（与固件一致）：URL 只需带 `device_id`（设备链路仅此一项鉴权，无 API Key / PIN）。
- **调试订阅**（`/camera_view`、`/device_pipeline` 订阅侧）：在 Web 控制台「调试台」登录后签发 `debug_token`，URL 带 `debug_token=...`（兼容参数名 `debugtoken` / `ws_token`）。
- **HTTP / 工具兜底**：`data/.free_api_key`（若存在）仅供本地联调脚本读取。

```bash
source .venv/bin/activate

# 推送 wav 测 /asr_chat 全链路
python tools/test_client.py \
  --ws-url "ws://127.0.0.1:9000/asr_chat?device_id=deskbot_dev" \
  --input-wav demo_16k_mono.wav

# 本机麦克风
python tools/live_mic_client.py \
  --ws-url "ws://127.0.0.1:9000/asr_chat?device_id=deskbot_dev"

# 推图片测 camera_frame
python tools/camera_test_client.py \
  --ws-url "ws://127.0.0.1:9000/asr_chat?device_id=deskbot_dev" \
  --image-dir ./samples

# 设备-服务端网络连通性 / 并发 / PB 延迟（须真实设备在线）
python tools/network_connectivity_test.py \
  --device-id deskbot_e8f60a8cf9b0 \
  --base-url http://127.0.0.1:9000 \
  --concurrent-sec 20
```

WAV 须 **16 kHz / mono / s16le**。

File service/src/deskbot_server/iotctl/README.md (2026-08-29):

# miot-ctl

轻量米家 IoT 命令行工具，基于 [miloco-miot](https://github.com/XiaoMi/xiaomi-miloco) SDK，**不依赖 Miloco 服务端**。

安装体积约 **50–80 MB**（仅 HTTP 控制所需依赖，无 opencv/onnx/感知模型）。

## 快速开始

```bash
# 1. 安装（自动下载 wheel + 创建虚拟环境）
bash install.sh

# 2. 绑定小米账号
./miot-ctl auth bind

# 授权后浏览器会跳到 https://127.0.0.1/?code=...&state=...
# 页面显示「无法访问」是正常的，复制地址栏完整 URL 执行：
./miot-ctl auth authorize "https://127.0.0.1/?code=...&state=..."

# 3. 列出设备
./miot-ctl device list

# 4. 查看设备能力
./miot-ctl device spec <did>

# 5. 控制设备
./miot-ctl device set <did> on true
./miot-ctl device set <did> brightness 60
./miot-ctl device props <did> brightness

# 6. 调用动作（如音箱播报）
./miot-ctl device action <did> play-text "你好"
```

## 目录结构

```
iotctl/
├── install.sh          # 一键安装
├── miot-ctl            # 启动脚本
├── requirements.txt    # 最小 Python 依赖
├── miot_ctl/           # 工具源码
├── wheels/             # install.sh 下载的 SDK wheel
└── .venv/              # 虚拟环境（install.sh 创建，本地生成）
```

**运行时数据（含 token）不入库**，默认写入：

```
service/data/miot-cli/               # 独立 CLI（auth bind 等）
service/data/{device_id}/miot/ # deskbot 网站 / LLM 按设备绑定
```

上述目录已在 `service/.gitignore` 中忽略，**禁止**提交 `auth.json` 等敏感文件。

## 拷贝到其他机器

整个 `miot-ctl/` 目录可以直接复制走。到新机器后：

```bash
cd miot-ctl
bash install.sh    # 若已带 wheels/ 和 .venv 可跳过，直接 ./miot-ctl
./miot-ctl auth status
```

迁移 CLI 登录态时拷贝 `service/data/miot-cli/`，或在新机器重新 `auth bind`。

也可自定义数据目录：

```bash
export MIOT_CTL_HOME=/path/to/your/data
./miot-ctl device list
```

## 命令参考

### 账号

| 命令 | 说明 |
|---|---|
| `auth bind` | 浏览器授权绑定 |
| `auth authorize <base64>` | 非交互提交授权码 |
| `auth status` | 查看绑定状态 |
| `auth unbind` | 解绑 |

### 设备

| 命令 | 说明 |
|---|---|
| `device list [--online] [--json]` | 设备列表 |
| `device get <did>` | 设备详情 |
| `device spec <did>` | 能力列表 |
| `device set <did> <key> <value>` | 写属性 |
| `device props <did> [key...]` | 读属性 |
| `device action <did> <key> [args...]` | 调用动作 |

`key` 支持：
- `type_name`：如 `on`、`brightness`、`color-temperature`
- `prop.{siid}.{piid}` / `action.{siid}.{aiid}`

`value` 自动推断类型：`true/false/on/off` → 布尔，纯数字 → 数值，其余 → 字符串。

### 场景

| 命令 | 说明 |
|---|---|
| `scene list` | 列出手动场景 |
| `scene run <scene_id>` | 触发场景 |

## 手动安装 wheel

若 `install.sh` 下载失败，可手动放置 wheel：

```bash
# 从 GitHub Release 下载对应平台 wheel，例如：
# miloco_miot-2026.7.3-py3-none-manylinux_2_28_x86_64.whl
mkdir -p wheels
cp /path/to/miloco_miot-*.whl wheels/
bash install.sh
```

## 许可

基于 Xiaomi Miloco / miloco-miot SDK，**仅限非商业用途**。详见上游 [LICENSE.md](https://github.com/XiaoMi/xiaomi-miloco/blob/main/LICENSE.md)。

## 故障排查

| 现象 | 处理 |
|---|---|
| `未绑定小米账号` | 运行 `auth bind` |
| `state 不匹配` | 重新 `auth bind`，不要复用旧授权码 |
| `设备 spec 中未找到` | 先 `device spec <did>` 查正确 key |
| 控制成功但设备无反应 | 看返回 JSON 中 `code` 负值和 `code_msg` |
| 安装慢 | 设置 `export UV_INDEX_URL=https://pypi.tuna.tsinghua.edu.cn/simple` |

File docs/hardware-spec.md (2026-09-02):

# Deskbot 硬件规格文档

> 产品名称：Deskbot（内部）/ Brufik（公开仓库）
> 固件版本：0.0.5

---

## 1. 主控平台

| 项目 | 规格 |
|---|---|
| 开发板 | **Seeed XIAO ESP32S3 Sense** → 自研 **Deskbot v2 主控板（PCB V2.0 Base，ESP32-S3-WROOM-1U-N16R8）**（引脚以 [`firmware/deskbot_config.h`](../hardware/firmware/deskbot_config.h) 为准；以下引脚均为 **PCB V2.0（Base）** 实际 GPIO，丝印即 GPIO 号，早期 XIAO 参考设计已废弃） |
| MCU | ESP32-S3（Xtensa 双核 LX7） |
| 框架 | Arduino-ESP32 3.3.9 + ESP-IDF 5.5.4 |
| PlatformIO 平台 | pioarduino 55.03.9 |
| PlatformIO 环境名 | `seeed_xiao_esp32s3` |
| Flash 容量 | 8MB |
| PSRAM | 已启用（CONFIG_SPIRAM=y） |
| WiFi | 2.4GHz 802.11 b/g/n（板载） |
| 串口波特率 | 115200（USB CDC） |

### Flash 分区表

| 分区 | 类型 | 偏移 | 大小 |
|---|---|---|---|
| nvs | data/nvs | 0x9000 | 20KB |
| otadata | data/ota | 0xe000 | 8KB |
| app0 | app/factory | 0x10000 | ~7MB |
| ffat | data/fat | 0x700000 | 1MB |

---

## 2. 显示屏

| 项目 | 规格 |
|---|---|
| 型号 | **Waveshare 1.83" LCD Rev2** |
| 驱动 IC | ST7789P（Adafruit_ST7789 驱动） |
| 原始分辨率 | 240 × 284 像素 |
| 显示分辨率 | **284 × 240** 像素（硬件旋转 3，横屏模式） |
| 色深 | RGB565（16-bit） |
| 接口 | SPI Mode 3，80MHz |
| 行偏移 | 36（DESKBOT_DISPLAY_ROW_OFFSET） |
| 列偏移 | 0（DESKBOT_DISPLAY_COL_OFFSET） |
| 亮度 | 最大（寄存器 0x51=255，0x53=0x2C） |
| RST/BL | 硬接 3.3V，不由 MCU 控制 |
| 顶部安全区 | 4 像素 |
| 画布内存 | PSRAM 分配，~133KB |
| 字体 | WenQuanYi 12px 位图字体（GB2312 子集，4400+ 字形） |
| 渲染层 | 6 层矢量动画（bg、nose、mouth、eye_l、eye_r、extra） |

### SPI 引脚分配

| 信号 | GPIO（v2 板） | 备注 |
|---|---|---|
| MOSI | 5 | — |
| SCK | 4 | — |
| CS | 6 | — |
| DC | 7 | — |
| RST | -- | 硬接 3.3V |
| BL | -- | 硬接 3.3V |

---

## 3. 摄像头

| 项目 | 规格 |
|---|---|
| 传感器 | **OV2640 / OV3660**（esp_camera 上电自动识别；v2.0 结构件配 **OV3660** 模组，引脚通用） |
| 镜头 | v2.0：**异面**，120° 广角，**40mm** 长度（旧 XIAO 版为同面 25mm） |
| 接口 | 8-bit 并行 + SCCB（I2C）控制 |
| XCLK 频率 | 10MHz（20MHz 会导致 DMA 损坏/绿屏） |
| 帧尺寸 | VGA 640×480（曾用 QVGA 320×240，画质差；OV3660 驱动上限远高于此） |
| 像素格式 | 传感器内 JPEG（硬件 JPEG） |
| JPEG 质量 | 8（0-63，越低越好） |
| 最大 JPEG 大小 | 256KB/帧（VGA+质量 8 最坏场景约 180KB） |
| 传感器锐化 | +2（-3..3 边缘增强，0=默认）；denoise 关闭（抹细节） |
| 帧缓冲 | 2 个缓冲区，位于 PSRAM |
| 抓取模式 | CAMERA_GRAB_WHEN_EMPTY |
| 默认帧率 | 1 FPS（1000ms 间隔，可服务端动态调整） |
| 预热 | 初始化后丢弃 30 帧（AWB/AGC 收敛） |
| 任务栈 | 16KB，优先级 3，绑定 APP_CPU_NUM |

### 摄像头引脚分配

| 信号 | GPIO |
|---|---|
| XCLK | 14 |
| PCLK | 48 |
| VSYNC | 11 |
| HREF | 12 |
| SIOD (SDA) | 9 |
| SIOC (SCL) | 10 |
| Y2 (D0) | 39 |
| Y3 (D1) | 18 |
| Y4 (D2) | 8 |
| Y5 (D3) | 17 |
| Y6 (D4) | 38 |
| Y7 (D5) | 47 |
| Y8 (D6) | 21 |
| Y9 (D7) | 13 |
| PWDN | -1（未使用） |
| RESET | -1（未使用） |

> 引脚以 `firmware/camera.cpp` 顶部宏为准（PCB V2.0 Base 实际布线）；上表原为 v1/XIAO 转接板旧值，勿再参考。

### 摄像头服务端配置

| 参数 | 默认值 | 范围 |
|---|---|---|
| frame_width | 640 | 160-640 |
| frame_height | 480 | 120-480 |
| horizontal_fov_deg | 120 | 30-170 |
| eye_yaw_range_deg | 50 | 10-90 |
| frontal_angle_threshold_deg | 15 | 1-90 |
| min_face_detection_confidence | 0.15 | - |
| num_faces | 5 | 1-10 |
| face_track_max_dist_px | 90 | 16-240 |
| face_track_max_lost_frames | 18 | 1-60 |
| face_embedding_enabled | true | bool |
| identity_similarity_threshold | 0.40 | 0.25-0.99 |

---

## 4. 舵机

| 项目 | X 轴（水平/左右） | Y 轴（垂直/上下） |
|---|---|---|
| 类型 | 3.7g 微型舵机（5V，20.2×8.5mm，JR2.54） | SG90 / 9g 舵机（JR2.54） |
| GPIO | 16 | 15 |
| 角度范围 | 0° - 180° | 70° - 110°（限位行程） |
| 中心位置 | 90° | 90° |
| 脉冲范围 | 1000μs - 2000μs | 1000μs - 2000μs |
| PWM 频率 | 50Hz（20ms 周期） | 50Hz（20ms 周期） |

- 驱动库：ESP32Servo（基于 MCPWM）
- 运动控制：时间预算线性插值，每 tick 更新
- 命令模式：绝对(0)、相对(1)、保持(2)
- 命令队列深度：50
- 任务栈：8KB，优先级 3，绑定 APP_CPU_NUM

### 舵机服务端配置

| 参数 | 默认值 |
|---|---|
| xMin | 0 |
| xMax | 180 |
| yMin | 70 |
| yMax | 110 |
| xReverse | 0 |
| yReverse | 0 |
| 视角模式 | viewer（观看者视角） |

---

## 5. 音频

### 扬声器（播放）

| 项目 | 规格 |
|---|---|
| 功放芯片 | **NS4168**（I2S 输入 D 类功放，v2 主控板板载，替代原 MAX98357A） |
| 扬声器 | 2011 型，8Ω 1W 腔体喇叭（1.25 插头） |
| I2S 总线 | I2S_NUM_1，STD 模式 |
| 采样率 | **16000Hz 统一下发**（moss 引擎 48k 由服务端降采样；豆包直连 16k；设备端"整块解码→播放"结构下 24k/48k 会进入解码预算边缘带） |
| 位深 | 16-bit |
| 声道 | 单声道（支持 WAV 立体声回放） |
| DMA 缓冲 | 6 × 240 帧（ESP_I2S 驱动固定，≈5.8KB；解码突发需小于其覆盖时长） |
| 默认音量 | 85%（范围 0-100） |
| 编解码 | PCM S16LE、Opus（下行解码） |
| 可听阈值 | mean_abs × volume ≥ 16 |
| 任务栈 | 28KB，优先级 7，绑定 APP_CPU_NUM |

### 麦克风（录音）

| 项目 | 规格 |
|---|---|
| 类型 | 板载 PDM 麦克风（v2 主控板板载，聆麦 LMD2718T271；原 Sense 扩展板方案已废弃） |
| I2S 总线 | I2S_NUM_0，PDM_RX 模式 |
| 采样率 | 16000Hz |
| 位深 | 16-bit |
| 声道 | 单声道 |
| 帧大小 | 320 样本 = 20ms @ 16kHz |
| 编码 | Opus，VOIP 模式，复杂度 0，码率 24kbps |
| 语音增强 | 高通滤波器（α=0.969）+ 5× 增益 |
| VAD | 能量门限 + EMA，触发比 1.3×，底噪阈值 140 |
| 上行批量 | 5 个 Opus 帧/WS 消息 |
| 最大连续上行 | 30 秒/段 |
| 任务栈 | 28KB，优先级 6，绑定 APP_CPU_NUM |

### 音频引脚分配

**扬声器 I2S（v2 板）：**

| 信号 | GPIO | 备注 |
|---|---|---|
| DIN | 40 | — |
| BCLK | 41 | — |
| LRC | 42 | — |
| SD (=AMP_CTRL) | 45 | 高电平使能（strapping 引脚，boot 后才可拉高） |
| GAIN | NC | 未连接 |

**麦克风 PDM（v2 板）：**

| 信号 | GPIO |
|---|---|
| CLK | 1 |
| DATA | 2 |

### VAD（语音活动检测）配置

| 参数 | 值 |
|---|-----|
| mode | 3 |
| frame_ms | 30 |
| min_speech_ms | 250 |
| max_silence_ms | 500 |
| pre_speech_ms | 300 |
| silero_threshold | 0.5 |
| silero_threshold_low | 0.2 |

---

## 6. XIAO ESP32S3 Pad-GPIO 映射（仅历史参考）

> 旧 XIAO 转接板方案使用，**已废弃**；v2 主控板丝印直接标 GPIO 号。

```
D0  = GPIO1    D1  = GPIO2    D2  = GPIO3    D3  = GPIO4
D4  = GPIO5    D5  = GPIO6    D6  = GPIO43   D7  = GPIO44
D8  = GPIO7    D9  = GPIO8    D10 = GPIO9
```

---

## 7. 电源要求

| 模块 | 电压 | 备注 |
|---|---|---|
| MCU + 显示屏 + 摄像头 | 3.3V | v2 主控板板载稳压，TYPE-C 5V 供电 |
| 舵机 | **5V ≥ 1A** | 独立供电，与逻辑共地 |
| NS4168 功放 | 5V（TYPE-C VBUS） | v2 主控板板载（D 类功放，替代原 MAX98357A） |
| USB-C 接口 | 5V | 主控 PCB V2.0（Base）上的 TYPE-C 16P（LCSC C2765186），CC1/CC2 5.1k 下拉电阻 |

**建议总供电：5V ≥ 1A**（舵机为主要电流消耗）

---

## 8. 通信协议总览

| 协议 | 用途 | 详情 |
|---|---|---|
| SPI | 显示屏驱动 | Mode 3，80MHz |
| I2S (STD) | 扬声器输出 | I2S_NUM_1，16kHz 16-bit 单声道 |
| I2S (PDM_RX) | 麦克风采集 | I2S_NUM_0，16kHz 16-bit PDM |
| SCCB/I2C | 摄像头控制 | SIOD=GPIO9, SIOC=GPIO10 |
| 8-bit 并行 | 摄像头数据 | D0-D7 + VSYNC/HREF/PCLK |
| PWM (MCPWM) | 舵机控制 | 50Hz, 1000-2000μs 脉冲 |
| WiFi | 网络连接 | STA 模式（正常）/ AP 模式（配网） |
| WebSocket | 云端通信 | ws:// 或 wss://，路径 /asr_chat |
| HTTP | 配网门户 | AP 模式下 WebServer 192.168.4.1 |
| USB CDC | 串口调试 | 115200 baud |

### WebSocket 协议细节

- 端点：`ws://<host>:<port>/asr_chat?device_id=<mac>`（仅 `device_id` 鉴权，无 API Key / PIN）
- 最大消息大小：1MB
- TCP 超时：15s，写超时：5s
- 线格式：`u32be(json_len) + json_utf8 + optional_binary`
- 服务端端口：9000
- Ping 间隔：120s，Ping 超时：300s

---

## 9. 音频处理（全双工）

- 音频前端集成 **ESP-SR AFE**（`audio_frontend_esp_sr.cpp`）：AEC 回声消除 / NS 降噪 / AGC / VAD
- **全双工**：已移除 speaker/mic 半双工互斥，播放时麦克风照常采集，机器人可以边听边说、随时被打断
- 上行统一 16kHz（`SAMPLE_RATE`），下行 TTS 音频同样统一 16kHz（config.yaml `tts.sample_rate`）；切句在服务端 Silero VAD

---

## 10. 关键注意事项

### ⚡ 电源
1. **舵机必须独立 5V 供电（≥1A）**，不可直接从 XIAO 板取电，否则会导致 MCU 复位或工作不稳定
2. 舵机电源与逻辑电源必须**共地**
3. USB-C 接口需确保 CC1/CC2 5.1k 下拉电阻焊接正确，否则无法被主机识别

### 🔌 引脚冲突
1. 舵机避开 USB 19/20 与 strapping 引脚：当前固件 X（左右）→ **GPIO16**（3.7g 小舵机）、Y（上下）→ **GPIO15**（9g 大舵机）
2. **PCB V2.0（Base）** 已按上述 GPIO 直接布线，按丝印焊接即可；早期 XIAO 转接板方案（舵机曾连到 D6/D7 UART0）已废弃
3. 板载 LED 引脚与音频/摄像头冲突，**不可用**

### 📷 摄像头
1. XCLK 必须为 **10MHz**，20MHz 会导致 ESP32-S3 上 DMA 损坏（绿屏）
2. 初始化后需丢弃 **30 帧**预热画面（AWB/AGC 收敛）
3. 120° 广角镜头会产生桶形畸变，服务端可配置去畸变（默认关闭）

### 🔊 音频
1. 音频前端含 **AEC / NS / AGC / VAD**（ESP-SR AFE），全双工采集，播放时不静音麦克风
2. AGC 压缩增益默认 12dB（`DESKBOT_AFE_AGC_COMPRESSION_GAIN_DB`），避免 AEC 残留抬过 VAD 阈值
3. Opus 编码复杂度设为 0（最低），优先保证实时性

### 🖥️ 显示屏
1. RST 和 BL 引脚**硬接 3.3V**，固件无法控制复位和背光
2. 横屏旋转后 X 起始位置需偏移 -18（DESKBOT_DISPLAY_ROT3_XSTART_ADJ）
3. 顶部有 4px 安全区，绘制内容应避开

### 📡 通信
1. WebSocket 最大帧 1MB，单帧 JPEG 最大 32KB
2. 下行 PB 帧最大 64KB JSON + 320KB 二进制（10s @ 16kHz PCM，统一下发采样率）
3. PB 帧间需 50ms 间隔，PB 块间需 150ms 间隔
4. WiFi 默认 SSID：`deskbot_wifi`，密码：`hello2026`

### 🔧 调试
1. USB CDC 串口波特率 115200
2. 配网模式：AP 热点，WebServer 地址 192.168.4.1
3. 固件支持命令行交互（通过串口）

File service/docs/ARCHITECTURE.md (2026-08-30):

# deskbot-server 架构（概要）

分层：**ws / web**（协议入口）→ **application**（用例）→ **core**（端口 Protocol）← **infrastructure**（ASR / LLM / TTS 实现）。**pb**、**vision** 不依赖 ws。

## 主链路（语音对话）

```
/asr_chat
  → VAD + 外部 funasr 服务（FunAsrAdapter，9102）
  → run_chat_turn
      → ensure_active_session（按 device 加载历史）
      → complete_llm_with_tool_loop（多轮 tools，最多 8 轮）
      → TTS（豆包 doubao）→ 音素口型
      → pb.wire 组包
      → DownlinkPort.send_pb_wire
```

摄像头：`camera_frame` + JPEG → `CameraFaceService` → 调试订阅 / 人脸跟踪 / 舵机跟随。

## 定时任务

```
ScheduledTaskScheduler（60s 轮询）
  → claim_due_tasks（SQLite scheduled_tasks，东八区 cron）
  → run_chat_turn（reuse_session_id，强制 TTS 提醒）
  → finish_scheduled_task
```

任务由 LLM `schedule_task` 工具创建；**不由服务端从用户话术正则推断**。

## 模块一览

| 目录 / 模块 | 职责 |
|---|---|
| `src/deskbot_server/ws/` | WebSocket 会话与流水线（`/asr_chat`、`/device_pipeline`、`/camera_view`）、pb 下行队列、鉴权门禁（device_id / debug_token） |
| `src/deskbot_server/web/` | FastAPI 控制台（`auth_bp`/`app_bp` 设备/任务/记忆/人脸，`app2c_bp` 2C 页面，`debug_bp` 调试） |
| `src/deskbot_server/controller/` | HTTP/WS 路由与鉴权装饰器（`require_device_ws` / `require_api_auth` / debug_token） |
| `src/deskbot_server/db/` | SQLAlchemy 模型（User、Device、ScheduledTask、DeviceUsage、DeviceProfileFace、DeviceMemory、DeviceSession 等） |
| `src/deskbot_server/service/user_service.py` | 注册/登录、设备绑定解绑、用户与设备列表 |
| `src/deskbot_server/service/live_service.py` | 在线设备 live 状态（wander/sleep/gaze），对话时暂停 |
| `src/deskbot_server/service/application/chat_flow.py` | 单轮对话编排（LLM + TTS + pb） |
| `src/deskbot_server/service/application/llm_tool_loop.py` | LLM 多轮 tool-call |
| `src/deskbot_server/service/application/llm_tool_runner.py` | 执行 `tools` 指令 |
| `src/deskbot_server/service/application/scheduled_task_scheduler.py` | 到期任务调度 |
| `src/deskbot_server/dao/device_session_mapper.py` | 对话 session（SQLite `device_session` 表） |
| `src/deskbot_server/utils/device_data.py` | 按设备解析 `data/{device_id}/` 数据目录；共享配置在 `data/global/` |
| `src/deskbot_server/pb/` | 表情、口型、舵机、wire 组包 |
| `src/deskbot_server/vision/` | 人脸检测、embedding、跟随 |
| `src/deskbot_server/infrastructure/` | ASR / LLM / TTS 适配实现 |

## WebSocket

| 路径 | 生产必需 |
|---|---|
| `/asr_chat?device_id=` | 是（`device_id` 必须，仅此一项鉴权） |
| `/camera_view`、`/device_pipeline` | 否（调试；Web 侧 debug token + 设备归属） |

单进程 asyncio；ASR 推理在外部 funasr 独立进程（funasr 完全独立化，v1.2.0 起主服务不再加载 FunASR）。重 CPU 走 `asyncio.to_thread`；人脸推理由 `max_concurrent_face_infer` 限流。

## 装配（`main.py`）

```
init_database()
build_chat_service()
DeviceWsService + LiveService + CameraFaceService + ScheduledTaskScheduler（60s 轮询）
uvicorn FastAPI (:9000)
```

Web 控制台默认由同进程 `mount_web` 挂载（`start.sh` 也可另起）。

## 测试

```bash
source .venv/bin/activate
pytest tests/ -q
```

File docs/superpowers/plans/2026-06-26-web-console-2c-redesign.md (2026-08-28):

# Web 控制台 2C 化改造 Implementation Plan

> **状态：历史实施计划（2026-06-26）。** 文中 Flask / `service/deskbot-server/` 路径已过时；当前为 FastAPI + `service/src/deskbot_server/`。保留仅供对照设计意图。

> **For agentic workers:** REQUIRED SUB-SKILL: Use superpowers:subagent-driven-development (recommended) or superpowers:executing-plans to implement this plan task-by-task. Steps use checkbox (`- [ ]`) syntax for tracking.

**Goal:** 在不改动核心管线/协议/固件的前提下，为 deskbot-server 增加一套消费级（2C）Web 外壳，把「表情」「声音」做成两个核心可玩页面，并把记忆/提醒/人/设备重新包装、把开发者功能收进「高级」。

**Architecture:** 纯前端为主。新增一个 `app2c_bp` 蓝图（仅渲染模板）+ 消费级母版 `base_2c.html` + 主题 `theme_2c.css`，页面用内联 Vue 调用**已存在**的 JSON 接口（`/api/doubao_tts/*`、`/api/face_expr_scenes`、`/app/api/*`）。后端 Phase 1 零新增；Phase 2 可选新增一个极小的 per-device 情绪→场景映射 store。

**Tech Stack:** Flask 3 + Jinja2 + 内联 Vue 3（CDN/vendored）+ 原生 CSS；图标内联 Lucide SVG；pytest。

参考来源：
- 设计 spec：`docs/superpowers/specs/2026-06-26-web-console-2c-redesign-design.md`
- 视觉/标记来源（真实可复制）：`web控制台-2C-原型.html`（仓库根目录）
- 既有测试风格：`service/deskbot-server/tests/test_endpoint_auth.py`

> 所有路径以 `service/deskbot-server/` 为根，除非另写明（如根目录的原型 HTML）。

---

## File Structure

新建：
- `src/deskbot_server/web/static/theme_2c.css` — 消费级主题（从原型 `<style>` 移植）。
- `src/deskbot_server/web/templates/base_2c.html` — 侧边栏外壳 + Lucide 图标宏 + `{% block content %}`。
- `src/deskbot_server/web/templates/app2c/home.html` — 首页「家」。
- `src/deskbot_server/web/templates/app2c/voice.html` — 声音（调既有 `/api/doubao_tts/*`）。
- `src/deskbot_server/web/templates/app2c/expr.html` — 表情（调既有 `/api/face_expr_scenes`）。
- `src/deskbot_server/web/templates/app2c/memories.html` — 它记得的事（调 `/app/api/memories`）。
- `src/deskbot_server/web/templates/app2c/reminders.html` — 提醒（调 `/app/api/scheduled-tasks`）。
- `src/deskbot_server/web/templates/app2c/people.html` — 认识的人（调 `/app/api/face-profiles`）。
- `src/deskbot_server/web/templates/app2c/devices.html` — 我的设备（调 `/app/api/devices`）。
- `src/deskbot_server/web/templates/app2c/advanced.html` — 高级 hub（链接既有页面）。
- `src/deskbot_server/web/blueprints/app2c_bp.py` — 仅渲染上述模板的蓝图。
- `tests/test_app2c_pages.py` — 路由鉴权 + 200 烟雾测试。

修改：
- `src/deskbot_server/web/app.py` — 注册 `app2c_bp`；登录后落地页指向 `/home`。

Phase 2（可选）新建：
- `src/deskbot_server/emotion_expr_map_store.py` — per-device 情绪→场景映射 store。
- `tests/test_emotion_expr_map_store.py` — store 单测。
- 在 `app2c_bp.py` 增加 `GET/POST /api/emotion_expr_map`。
- `tests/test_emotion_expr_map_api.py` — 接口测试。

---

## Phase 0 — 外壳与蓝图

### Task 1: 消费级主题 theme_2c.css

**Files:**
- Create: `src/deskbot_server/web/static/theme_2c.css`

- [ ] **Step 1: 从原型移植样式**

打开仓库根目录 `web控制台-2C-原型.html`，复制其 `<style>…</style>` 标签**内部**的全部 CSS，原样粘贴到 `theme_2c.css`。该 CSS 已包含 `.app/.side/.navi/.stage/.hero/.mini/.vgrid/.vcard/.maprow/.thumb/.toast` 等全部类，且使用 `:root` 变量，无需改动。

- [ ] **Step 2: 校验文件非空且含关键类**

Run: `grep -c -E '\.side|\.navi|\.vgrid|\.thumb' src/deskbot_server/web/static/theme_2c.css`
Expected: 输出 ≥ 4

- [ ] **Step 3: Commit**

```bash
git add src/deskbot_server/web/static/theme_2c.css
git commit -m "feat(web2c): add consumer theme_2c.css ported from prototype"
```

---

### Task 2: 母版 base_2c.html（侧边栏 + Lucide 图标宏）

**Files:**
- Create: `src/deskbot_server/web/templates/base_2c.html`

- [ ] **Step 1: 写母版骨架**

创建 `base_2c.html`，内容如下（侧边栏导航 + 图标宏 + 内容块）。导航项的 `active_nav` 由各页传入。Lucide SVG 路径与原型一致（可从原型 `<nav class="navi">` 与图标处复制；下面已内联常用项）。

```html
{% macro icon(name) -%}
{% if name == 'home' %}<svg viewBox="0 0 24 24"><path d="M3 11l9-8 9 8"/><path d="M5 10v10h14V10"/></svg>
{% elif name == 'expr' %}<svg viewBox="0 0 24 24"><circle cx="12" cy="12" r="9"/><path d="M8.5 14c1 1.3 6 1.3 7 0"/><circle cx="9" cy="10" r="1"/><circle cx="15" cy="10" r="1"/></svg>
{% elif name == 'voice' %}<svg viewBox="0 0 24 24"><path d="M11 5L6 9H3v6h3l5 4z"/><path d="M16 9a4 4 0 010 6"/><path d="M19 6a8 8 0 010 12"/></svg>
{% elif name == 'memory' %}<svg viewBox="0 0 24 24"><path d="M6 3h12a1 1 0 011 1v16l-7-4-7 4V4a1 1 0 011-1z"/></svg>
{% elif name == 'remind' %}<svg viewBox="0 0 24 24"><circle cx="12" cy="12" r="9"/><path d="M12 7v5l3 2"/></svg>
{% elif name == 'people' %}<svg viewBox="0 0 24 24"><circle cx="12" cy="8" r="4"/><path d="M4 20c0-4 4-6 8-6s8 2 8 6"/></svg>
{% elif name == 'device' %}<svg viewBox="0 0 24 24"><rect x="6" y="3" width="12" height="18" rx="2"/><path d="M11 18h2"/></svg>
{% elif name == 'advanced' %}<svg viewBox="0 0 24 24"><circle cx="12" cy="12" r="3"/><path d="M19.4 13a7 7 0 000-2l2-1.5-2-3.4-2.3 1a7 7 0 00-1.7-1L15 3h-4l-.7 2.6a7 7 0 00-1.7 1l-2.3-1-2 3.4L4.6 11a7 7 0 000 2l-2 1.5 2 3.4 2.3-1a7 7 0 001.7 1L11 21h4l.7-2.6a7 7 0 001.7-1l2.3 1 2-3.4z"/></svg>
{% endif %}
{%- endmacro %}
<!DOCTYPE html>
<html lang="zh-CN">
<head>
  <meta charset="UTF-8">
  <meta name="viewport" content="width=device-width, initial-scale=1.0">
  <title>{% block page_title %}小歪 · 我的桌搭子{% endblock %}</title>
  <link rel="stylesheet" href="{{ url_for('static', filename='theme_2c.css') }}">
  {% block extra_head %}{% endblock %}
</head>
<body>
<div class="app">
  <aside class="side">
    <div class="brand"><div class="logo">歪</div><div><b>小歪</b><small>我的桌搭子</small></div></div>
    <nav class="navi">
      <a href="{{ url_for('app2c.home') }}" class="navlink {{ 'on' if active_nav=='home' }}">{{ icon('home') }}家</a>
      <div class="lbl">核心玩法</div>
      <a href="{{ url_for('app2c.expr') }}" class="navlink {{ 'on' if active_nav=='expr' }}">{{ icon('expr') }}表情</a>
      <a href="{{ url_for('app2c.voice') }}" class="navlink {{ 'on' if active_nav=='voice' }}">{{ icon('voice') }}声音</a>
      <div class="lbl">日常</div>
      <a href="{{ url_for('app2c.memories') }}" class="navlink {{ 'on' if active_nav=='memory' }}">{{ icon('memory') }}它记得的事</a>
      <a href="{{ url_for('app2c.reminders') }}" class="navlink {{ 'on' if active_nav=='remind' }}">{{ icon('remind') }}提醒</a>
      <a href="{{ url_for('app2c.people') }}" class="navlink {{ 'on' if active_nav=='people' }}">{{ icon('people') }}认识的人</a>
      <a href="{{ url_for('app2c.devices') }}" class="navlink {{ 'on' if active_nav=='device' }}">{{ icon('device') }}我的设备</a>
      
      <a href="{{ url_for('app2c.advanced') }}" class="navlink {{ 'on' if active_nav=='advanced' }}">{{ icon('advanced') }}高级</a>
    </nav>
    <div class="foot"><div class="userchip"><div class="ua">歪</div><div><b>{{ nav_display_name or '我' }}</b><small>{{ nav_user_email or '' }}</small></div></div></div>
  </aside>
  <main>{% block content %}{% endblock %}</main>
</div>
{% block scripts %}{% endblock %}
</body>
</html>
```

- [ ] **Step 2: 在 theme_2c.css 末尾补 `.navlink` 样式**（原型用 `<button>`，母版用 `<a>`）

把原型中 `.navi button` 的样式追加一份 `.navi .navlink` 等价规则到 `theme_2c.css` 末尾：

```css
.navi .navlink{display:flex;align-items:center;gap:11px;text-decoration:none;
  padding:10px 12px;border-radius:11px;font-size:14px;color:var(--dim);font-weight:600}
.navi .navlink:hover{background:#f6f6fc;color:var(--ink)}
.navi .navlink.on{background:var(--brand-soft);color:var(--brand)}
.navi .navlink svg{width:19px;height:19px;stroke:currentColor;fill:none;stroke-width:1.7;stroke-linecap:round;stroke-linejoin:round;flex:none}
```

- [ ] **Step 3: Commit**

```bash
git add src/deskbot_server/web/templates/base_2c.html src/deskbot_server/web/static/theme_2c.css
git commit -m "feat(web2c): add base_2c shell with sidebar + lucide icon macro"
```

---

### Task 3: app2c 蓝图 + 注册 + 登录落地页

**Files:**
- Create: `src/deskbot_server/web/blueprints/app2c_bp.py`
- Modify: `src/deskbot_server/web/app.py`
- Test: `tests/test_app2c_pages.py`

- [ ] **Step 1: 写失败测试**

```python
# tests/test_app2c_pages.py
from __future__ import annotations

import tempfile
from pathlib import Path

import pytest

@pytest.fixture()
def temp_db(monkeypatch):
    with tempfile.TemporaryDirectory() as tmp:
        db_path = Path(tmp) / "test.db"
        monkeypatch.setenv("DESKBOT_DB_PATH", str(db_path))
        from deskbot_server.db import init_database
        from deskbot_server.db.engine import init_engine, reset_engine

        reset_engine()
        init_engine(db_path)
        init_database()
        yield db_path

def _login_client():
    from deskbot_server.auth.service import create_user
    from deskbot_server.web.app import create_app

    create_user("u2c@example.com", "password1234")
    app = create_app()
    client = app.test_client()
    client.post("/login", data={"email": "u2c@example.com", "password": "password1234"})
    return client

PAGES = ["/home", "/voice", "/expr", "/my/memories", "/my/reminders", "/my/people", "/my/devices", "/advanced"]

def test_2c_pages_redirect_when_anonymous(temp_db):
    from deskbot_server.web.app import create_app

    client = create_app().test_client()
    assert client.get("/home").status_code == 302

@pytest.mark.parametrize("path", PAGES)
def test_2c_pages_render_when_logged_in(temp_db, path):
    resp = _login_client().get(path)
    assert resp.status_code == 200
```

- [ ] **Step 2: 运行确认失败**

Run: `cd service/deskbot-server && python -m pytest tests/test_app2c_pages.py -q`
Expected: FAIL（路由不存在 → 404/302 不匹配，或 import 错误）

- [ ] **Step 3: 写蓝图**

```python
# src/deskbot_server/web/blueprints/app2c_bp.py
from __future__ import annotations

from flask import Blueprint, render_template
from flask_login import login_required

bp = Blueprint("app2c", __name__)

@bp.get("/home")
@login_required
def home():
    return render_template("app2c/home.html", active_nav="home")

@bp.get("/voice")
@login_required
def voice():
    return render_template("app2c/voice.html", active_nav="voice")

@bp.get("/expr")
@login_required
def expr():
    return render_template("app2c/expr.html", active_nav="expr")

@bp.get("/my/memories")
@login_required
def memories():
    return render_template("app2c/memories.html", active_nav="memory")

@bp.get("/my/reminders")
@login_required
def reminders():
    return render_template("app2c/reminders.html", active_nav="remind")

@bp.get("/my/people")
@login_required
def people():
    return render_template("app2c/people.html", active_nav="people")

@bp.get("/my/devices")
@login_required
def devices():
    return render_template("app2c/devices.html", active_nav="device")

@bp.get("/advanced")
@login_required
def advanced():
    return render_template("app2c/advanced.html", active_nav="advanced")
```

- [ ] **Step 4: 创建 8 个最小模板占位**（让路由先能渲染，内容后续任务填充）

为 `templates/app2c/` 下 8 个文件各写最小骨架，例如 `home.html`：

```html
{% extends "base_2c.html" %}
{% block content %}<div class="pagehd"><div><h1>家</h1></div></div>{% endblock %}
```

其余 7 个同样 `{% extends "base_2c.html" %}` + 一个 `<h1>`（标题分别为 表情/声音/它记得的事/提醒/认识的人/我的设备/高级），`active_nav` 已由路由传入。

- [ ] **Step 5: 注册蓝图并把登录落地页指向 /home**

修改 `src/deskbot_server/web/app.py`：

在 `app.register_blueprint(app_bp)` 之后新增一行：

```python
    from deskbot_server.web.blueprints.app2c_bp import bp as app2c_bp
    app.register_blueprint(app2c_bp)
```

并把 `login_manager.login_view` 后续登录成功的跳转指向 `/home`：在 `auth_bp` 登录成功默认 `next` 为 `/home`。**最小改动**：在 `app.py` 的 `require_auth` 中，已登录用户访问 `/` 时重定向到 `app2c.home`：

```python
        if path == "/" and current_user.is_authenticated:
            return redirect(url_for("app2c.home"))
```

（放在 `require_auth` 内、`if path == "/" or path.startswith(...)` 判断**之前**。）

- [ ] **Step 6: 运行测试确认通过**

Run: `cd service/deskbot-server && python -m pytest tests/test_app2c_pages.py -q`
Expected: PASS（9 个用例）

- [ ] **Step 7: Commit**

```bash
git add src/deskbot_server/web/blueprints/app2c_bp.py src/deskbot_server/web/app.py \
        src/deskbot_server/web/templates/app2c/ tests/test_app2c_pages.py
git commit -m "feat(web2c): add app2c blueprint, 8 page routes, smoke tests"
```

---

## Phase 1 — 页面接线（调用既有接口）

> 各页 markup 以根目录 `web控制台-2C-原型.html` 对应 `<section>` 为视觉来源：把该 section 的内部 HTML 放进对应模板的 `{% block content %}`，再按下方把"写死的数据"换成 Vue 拉取既有接口。每个任务完成后手动验收：登录后访问页面、按描述交互。

### Task 4: 首页「家」

**Files:**
- Modify: `src/deskbot_server/web/templates/app2c/home.html`

- [ ] **Step 1: 移植首页 markup**

把原型 `<section class="screen on" id="home">` 的**内部** HTML 复制进 `home.html` 的 `{% block content %}`。把卡片上的 `onclick="go('xxx')"` 改成真实链接：用 `<a href="{{ url_for('app2c.voice') }}">` 等包裹英雄卡/日常卡，或改 `onclick="location.href='…'"`。

- [ ] **Step 2: 手动验收**

启动 web：`cd service/deskbot-server && DESKBOT_WEB_PORT=5050 python -m deskbot_server.web`，登录后访问 `/home`：应见机器人大脸 + 两张英雄卡 + 四个日常入口，点击可跳到对应页面。

- [ ] **Step 3: Commit**

```bash
git add src/deskbot_server/web/templates/app2c/home.html
git commit -m "feat(web2c): home page with hero + daily entries"
```

---

### Task 5: 声音页（调 /api/doubao_tts/*）

**Files:**
- Modify: `src/deskbot_server/web/templates/app2c/voice.html`

接口契约（已存在，见 spec §3）：
- `GET /api/doubao_tts/speakers` → `{ok, speakers:[{label,id,scene,resource_id}]}`
- `GET /api/doubao_tts/config` → `{ok, config:{speaker, ...}}`
- `POST /api/doubao_tts/config` body `{speaker, resource_id}` → 设当前音色
- `POST /api/doubao_tts/synthesize` body `{text, speaker, resource_id}` → `{ok, wav_base64, sample_rate}`

- [ ] **Step 1: 写页面 + Vue 接线**

`voice.html`：

```html
{% extends "base_2c.html" %}
{% block page_title %}声音 · 小歪{% endblock %}
{% block extra_head %}<script src="{{ url_for('static', filename='vendor/vue.global.prod.min.js') }}"></script>{% endblock %}
{% block content %}
<div class="pagehd"><div><h1>声音</h1><p>挑一个喜欢的音色，点试听，满意就设为当前。</p></div></div>
<div id="app">
  <div v-for="(list, scene) in grouped" :key="scene">
    <div class="scene-h">[[ scene ]]</div>
    <div class="vgrid">
      <div class="vcard" :class="{cur: v.id===current}" v-for="v in list" :key="v.id">
        <span class="curtag" v-if="v.id===current">当前</span>
        <b>[[ v.label ]]</b><small>[[ v.scene ]]</small>
        <div class="vbtns">
          <button class="vbtn play" @click="preview(v)">[[ playing===v.id ? '播放中…' : '▶ 试听' ]]</button>
          <button class="vbtn set" @click="setCurrent(v)">[[ v.id===current ? '使用中' : '设为当前' ]]</button>
        </div>
      </div>
    </div>
  </div>
  <div class="slider-card">
    <div class="t"><span>试听音量</span><span>[[ vol ]]</span></div>
    <input type="range" min="0" max="100" v-model.number="vol">
  </div>
  <p class="lead" v-if="msg">[[ msg ]]</p>
</div>
{% endblock %}
{% block scripts %}
<script>
const { createApp } = Vue;
createApp({
  delimiters: ['[[', ']]'],
  data(){ return { speakers:[], current:'', playing:'', vol:80, msg:'' }; },
  computed:{
    grouped(){ const g={}; for(const v of this.speakers){ (g[v.scene||'其他'] ||= []).push(v); } return g; }
  },
  methods:{
    async load(){
      const s = await (await fetch('/api/doubao_tts/speakers')).json();
      this.speakers = s.speakers || [];
      const c = await (await fetch('/api/doubao_tts/config')).json();
      this.current = (c.config && c.config.speaker) || '';
    },
    async setCurrent(v){
      const r = await (await fetch('/api/doubao_tts/config', {method:'POST',
        headers:{'Content-Type':'application/json'},
        body: JSON.stringify({speaker:v.id, resource_id:v.resource_id})})).json();
      if(r.ok){ this.current = v.id; this.msg = '已设为当前音色：'+v.label; }
      else { this.msg = '设置失败：'+(r.error||''); }
    },
    async preview(v){
      this.playing = v.id; this.msg='';
      try{
        const r = await (await fetch('/api/doubao_tts/synthesize', {method:'POST',
          headers:{'Content-Type':'application/json'},
          body: JSON.stringify({text:'你好，我是你的桌搭子小歪。', speaker:v.id, resource_id:v.resource_id})})).json();
        if(r.ok && r.wav_base64){ const a=new Audio('data:audio/wav;base64,'+r.wav_base64); a.volume=this.vol/100; a.play(); }
        else { this.msg='试听失败：'+(r.error||''); }
      } finally { this.playing=''; }
    },
  },
  mounted(){ this.load(); },
}).mount('#app');
</script>
{% endblock %}
```

> 说明：`vue.global.prod.min.js` 已存在于 `static/vendor/`。用 `[[ ]]` 分隔符避免与 Jinja `{{ }}` 冲突。
> 音量：本任务的滑杆控制**试听播放音量**（浏览器端 `Audio.volume`），真实可用。设备「说话音量」的持久化目前无确认的既有写入接口（音量是 LLM 每轮 JSON 字段 / 设备侧），故不在本期内伪造；若后续需要，再确认/新增一个持久化音量接口（与 §7.2 同样的薄接口方式）。

- [ ] **Step 2: 手动验收**

登录后访问 `/voice`：音色按场景分组显示；点「▶ 试听」能听到声音（需 TTS 服务在线 + 已配 `DOUBAO_TTS_API_KEY`）；点「设为当前」后该卡显示「当前」。

- [ ] **Step 3: Commit**

```bash
git add src/deskbot_server/web/templates/app2c/voice.html
git commit -m "feat(web2c): voice page (gallery + preview + set-current) via existing endpoints"
```

---

### Task 6: 表情页（调 /api/face_expr_scenes）

**Files:**
- Modify: `src/deskbot_server/web/templates/app2c/expr.html`

接口契约（已实测确认）：
- `GET /api/face_expr_scenes?device_id=<id>` → `{ok, config:[{name,title,frames:[{ms,elements}]}], exists, file, device_id}`（场景在 **`config`** 键下）
- `POST /api/face_expr_scenes` body `{device_id, scenes:[…]}` → 保存（端点用 `_effective_device_id` 从 body 读 `device_id`，用 `normalize_face_expr_scenes` 从 body 读 `scenes`，两者均兼容）
- 当前设备：`GET /app/api/devices` → `{ok, current_device_id}`

- [ ] **Step 1: 写页面 + Vue（皮肤选择 + 客户端预览 + 保存）**

`expr.html`：

```html
{% extends "base_2c.html" %}
{% block page_title %}表情 · 小歪{% endblock %}
{% block extra_head %}<script src="{{ url_for('static', filename='vendor/vue.global.prod.min.js') }}"></script>{% endblock %}
{% block content %}
<div class="pagehd"><div><h1>表情</h1><p>挑一个面孔风格，右侧大屏实时预览。</p></div>
  <button class="btn primary" @click="save" id="saveBtn">保存表情</button></div>
<div id="app">
  <div class="exprgrid">
    <div class="stage" style="min-height:280px">
      <div class="face" style="width:260px;height:200px">
        <svg width="220" height="170" viewBox="0 0 120 80" v-html="previewSvg"></svg>
      </div>
    </div>
    <div>
      <div class="blocktitle" style="margin-top:0">面孔风格（场景）</div>
      <div class="thumbs">
        <div class="thumb" :class="{sel: i===selected}" v-for="(s,i) in scenes" :key="s.name"
             @click="selected=i">[[ s.title || s.name ]]</div>
      </div>
    </div>
  </div>
  <p class="lead" v-if="msg">[[ msg ]]</p>
</div>
{% endblock %}
{% block scripts %}
<script>
const { createApp } = Vue;
createApp({
  delimiters:['[[',']]'],
  data(){ return { scenes:[], selected:0, deviceId:'', msg:'' }; },
  computed:{
    previewSvg(){
      const s=this.scenes[this.selected]; if(!s||!s.frames||!s.frames[0]) return '';
      const el=s.frames[0].elements||{}; let out='';
      const draw=(arr,color)=>{ for(const p of (arr||[])){
        if(p.shape&&p.shape.indexOf('ellipse')===0) out+=`<ellipse cx="${p.x}" cy="${p.y}" rx="${p.rw}" ry="${p.rh}" fill="${color}"/>`;
        else if(p.shape==='line') out+=`<line x1="${p.x1}" y1="${p.y1}" x2="${p.x2}" y2="${p.y2}" stroke="${color}" stroke-width="2"/>`;
        else if(p.shape&&p.shape.indexOf('round_rect')===0) out+=`<rect x="${p.x}" y="${p.y}" width="${p.w}" height="${p.h}" rx="${p.radius||1}" fill="none" stroke="${color}" stroke-width="2"/>`;
      }};
      draw(el.eye_l,'#7fe7ff'); draw(el.eye_r,'#7fe7ff'); draw(el.mouth,'#ff9ec4'); draw(el.extra,'#ffd36b');
      return out;
    }
  },
  methods:{
    async load(){
      const d = await (await fetch('/app/api/devices')).json();
      this.deviceId = d.current_device_id || '';
      if(!this.deviceId){ this.msg='请先在「我的设备」选择一台设备'; return; }
      const r = await (await fetch('/api/face_expr_scenes?device_id='+encodeURIComponent(this.deviceId))).json();
      this.scenes = r.config || [];   // 场景在 config 键下（已实测）
    },
    async save(){
      if(!this.deviceId){ this.msg='没有当前设备，无法保存'; return; }
      const r = await (await fetch('/api/face_expr_scenes', {method:'POST',
        headers:{'Content-Type':'application/json'},
        body: JSON.stringify({device_id:this.deviceId, scenes:this.scenes})})).json();
      this.msg = r.ok ? '表情已保存到这台设备' : ('保存失败：'+(r.error||''));
    },
  },
  mounted(){ this.load(); },
}).mount('#app');
</script>
{% endblock %}
```

> 预览 `viewBox="0 0 120 80"` 与场景图元坐标范围匹配（图元 x≈0–90、y≈0–55）。接口形状已实测，无需再猜。

- [ ] **Step 2: 手动验收**

先在 `/my/devices` 绑定/选中一台设备，再访问 `/expr`：左侧大屏显示选中场景的首帧；点击不同「场景」缩略图，预览实时切换；点「保存表情」提示已保存。用 `GET /api/face_expr_scenes?device_id=…` 复核已写回。

- [ ] **Step 3: Commit**

```bash
git add src/deskbot_server/web/templates/app2c/expr.html
git commit -m "feat(web2c): expression page (scene picker + client preview + save)"
```

---

### Task 7: 它记得的事（调 /app/api/memories）

**Files:**
- Modify: `src/deskbot_server/web/templates/app2c/memories.html`

接口（已存在，用 session 当前设备）：`GET /app/api/memories`、`POST /app/api/memories` `{text}`、`DELETE /app/api/memories/<id>`。

- [ ] **Step 1: 写页面 + Vue（列表/新增/删除）**

```html
{% extends "base_2c.html" %}
{% block page_title %}它记得的事 · 小歪{% endblock %}
{% block extra_head %}<script src="{{ url_for('static', filename='vendor/vue.global.prod.min.js') }}"></script>{% endblock %}
{% block content %}
<div class="pagehd"><div><h1>它记得的事</h1><p>机器人记住的关于你的小事，随时可改可删。</p></div></div>
<div id="app">
  <div style="display:flex;gap:8px;margin-bottom:14px;max-width:560px">
    <input v-model="draft" placeholder="加一条它该记住的事…" style="flex:1;padding:10px 12px;border:1px solid var(--line);border-radius:12px">
    <button class="btn primary" @click="add">添加</button>
  </div>
  <div class="colwrap">
    <div class="note" v-for="m in items" :key="m.id">
      <p>[[ m.text ]]</p>
      <small>[[ m.created_at_fmt || '' ]]</small>
      <button class="btn ghost" style="margin-top:8px" @click="del(m)">删除</button>
    </div>
  </div>
  <p class="lead" v-if="msg">[[ msg ]]</p>
</div>
{% endblock %}
{% block scripts %}
<script>
const { createApp } = Vue;
createApp({
  delimiters:['[[',']]'],
  data(){ return { items:[], draft:'', msg:'' }; },
  methods:{
    async load(){ const r=await (await fetch('/app/api/memories')).json();
      if(r.ok) this.items=r.memories||[]; else this.msg=r.error||'加载失败'; },
    async add(){ const t=this.draft.trim(); if(!t) return;
      const r=await (await fetch('/app/api/memories',{method:'POST',headers:{'Content-Type':'application/json'},body:JSON.stringify({text:t})})).json();
      if(r.ok){ this.draft=''; this.load(); } else this.msg=r.error||'添加失败'; },
    async del(m){ const r=await (await fetch('/app/api/memories/'+m.id,{method:'DELETE'})).json();
      if(r.ok) this.load(); else this.msg=r.error||'删除失败'; },
  },
  mounted(){ this.load(); },
}).mount('#app');
</script>
{% endblock %}
```

- [ ] **Step 2: 手动验收**：`/my/memories` 能列出、添加、删除记忆（需已选当前设备）。

- [ ] **Step 3: Commit**

```bash
git add src/deskbot_server/web/templates/app2c/memories.html
git commit -m "feat(web2c): memories page via existing /app/api/memories"
```

---

### Task 8: 提醒 / 认识的人 / 我的设备（只读 + 删除/绑定）

**Files:**
- Modify: `src/deskbot_server/web/templates/app2c/reminders.html`
- Modify: `src/deskbot_server/web/templates/app2c/people.html`
- Modify: `src/deskbot_server/web/templates/app2c/devices.html`

接口（已存在）：`GET /app/api/scheduled-tasks` + `DELETE /app/api/scheduled-tasks/<id>`；`GET /app/api/face-profiles` + `DELETE /app/api/face-profiles/<person_id>`；`GET /app/api/devices` + `POST /app/api/devices` `{device_id,display_name}` + `POST /app/api/devices/select` `{device_id}`。

- [ ] **Step 1: reminders.html**

```html
{% extends "base_2c.html" %}
{% block page_title %}提醒 · 小歪{% endblock %}
{% block extra_head %}<script src="{{ url_for('static', filename='vendor/vue.global.prod.min.js') }}"></script>{% endblock %}
{% block content %}
<div class="pagehd"><div><h1>提醒</h1><p>它会在这些时间主动叫你。</p></div></div>
<div id="app">
  <div class="tl" v-for="t in tasks" :key="t.id">
    
    <div class="body"><b>[[ t.description || t.title || '提醒' ]]</b>
      <small>[[ (t.cron_expr || t.cron || '') + ' · 下次 ' + (t.next_run_at || '') ]]</small>
      <button class="btn ghost" style="margin-top:8px" @click="del(t)">删除</button>
    </div>
  </div>
  <p class="lead" v-if="!tasks.length">还没有提醒。</p>
</div>
{% endblock %}
{% block scripts %}
<script>
const { createApp } = Vue;
createApp({ delimiters:['[[',']]'], data(){return{tasks:[]};},
  methods:{ async load(){ const r=await (await fetch('/app/api/scheduled-tasks')).json(); if(r.ok) this.tasks=r.tasks||[]; },
    async del(t){ const r=await (await fetch('/app/api/scheduled-tasks/'+t.id,{method:'DELETE'})).json(); if(r.ok) this.load(); } },
  mounted(){ this.load(); } }).mount('#app');
</script>
{% endblock %}
```

> 任务对象由 `_task_to_dict()` 生成，含 `id/description/cron_expr/next_run_at/enabled` 等；模板已用 `||` 回退兼容 `cron`。

- [ ] **Step 2: people.html**

```html
{% extends "base_2c.html" %}
{% block page_title %}认识的人 · 小歪{% endblock %}
{% block extra_head %}<script src="{{ url_for('static', filename='vendor/vue.global.prod.min.js') }}"></script>{% endblock %}
{% block content %}
<div class="pagehd"><div><h1>认识的人</h1><p>机器人通过摄像头认识的人。</p></div></div>
<div id="app">
  <div class="people">
    <div class="person" v-for="p in profiles" :key="p.person_id">
      <div class="pa" style="background:linear-gradient(135deg,#6c5ce7,#a18bff)">[[ (p.name||'?').slice(0,1) ]]</div>
      <b>[[ p.name || ('#'+p.person_id) ]]</b>
      <button class="btn ghost" style="margin-top:6px" @click="del(p)">删除</button>
    </div>
  </div>
  <p class="lead" v-if="!profiles.length">还没有认识的人。</p>
</div>
{% endblock %}
{% block scripts %}
<script>
const { createApp } = Vue;
createApp({ delimiters:['[[',']]'], data(){return{profiles:[]};},
  methods:{ async load(){ const r=await (await fetch('/app/api/face-profiles')).json(); if(r.ok) this.profiles=r.profiles||[]; },
    async del(p){ const r=await (await fetch('/app/api/face-profiles/'+p.person_id,{method:'DELETE'})).json(); if(r.ok) this.load(); } },
  mounted(){ this.load(); } }).mount('#app');
</script>
{% endblock %}
```

> `person_id` / `name` 字段名以 `GET /app/api/face-profiles` 实际返回为准。

- [ ] **Step 3: devices.html**

```html
{% extends "base_2c.html" %}
{% block page_title %}我的设备 · 小歪{% endblock %}
{% block extra_head %}<script src="{{ url_for('static', filename='vendor/vue.global.prod.min.js') }}"></script>{% endblock %}
{% block content %}
<div class="pagehd"><div><h1>我的设备</h1><p>绑定与切换你的 Brufik 机器人。</p></div></div>
<div id="app">
  <div class="dev" v-for="d in devices" :key="d.device_id">
    <div class="di">🤖</div>
    <div style="flex:1"><b>[[ d.display_name ]]</b><br><small>[[ d.device_id ]]</small></div>
    <button class="btn" :class="d.device_id===current?'primary':'ghost'" @click="select(d)">[[ d.device_id===current?'当前':'切换' ]]</button>
  </div>
  <div style="display:flex;gap:8px;margin-top:14px;max-width:560px">
    <input v-model="newId" placeholder="设备 ID" style="flex:1;padding:10px 12px;border:1px solid var(--line);border-radius:12px">
    <button class="btn primary" @click="bind">绑定</button>
  </div>
  <p class="lead" v-if="msg">[[ msg ]]</p>
</div>
{% endblock %}
{% block scripts %}
<script>
const { createApp } = Vue;
createApp({ delimiters:['[[',']]'], data(){return{devices:[],current:'',newId:'',msg:''};},
  methods:{
    async load(){ const r=await (await fetch('/app/api/devices')).json(); if(r.ok){ this.devices=r.devices||[]; this.current=r.current_device_id||''; } },
    async select(d){ const r=await (await fetch('/app/api/devices/select',{method:'POST',headers:{'Content-Type':'application/json'},body:JSON.stringify({device_id:d.device_id})})).json(); if(r.ok){ this.current=r.current_device_id; } },
    async bind(){ const id=this.newId.trim(); if(!id) return; const r=await (await fetch('/app/api/devices',{method:'POST',headers:{'Content-Type':'application/json'},body:JSON.stringify({device_id:id})})).json(); if(r.ok){ this.newId=''; this.load(); } else this.msg=r.error||'绑定失败'; } },
  mounted(){ this.load(); } }).mount('#app');
</script>
{% endblock %}
```

> 设备图标 `🤖` 是内容占位，可换成 Lucide `device` 宏（`{{ icon('device') }}` 需在 macro 作用域内；如不便，保留中性图形）。

- [ ] **Step 4: 手动验收**：三页分别能列出提醒/人/设备，删除/绑定/切换生效。

- [ ] **Step 5: Commit**

```bash
git add src/deskbot_server/web/templates/app2c/reminders.html \
        src/deskbot_server/web/templates/app2c/people.html \
        src/deskbot_server/web/templates/app2c/devices.html
git commit -m "feat(web2c): reminders/people/devices pages via existing /app/api/*"
```

---

### Task 9: 高级 hub

**Files:**
- Modify: `src/deskbot_server/web/templates/app2c/advanced.html`

- [ ] **Step 1: 写 hub（链接既有页面，不迁移路由）**

```html
{% extends "base_2c.html" %}
{% block page_title %}高级 · 小歪{% endblock %}
{% block content %}
<div class="pagehd"><div><h1>高级</h1><p>开发者与进阶设置，普通使用一般用不到。</p></div></div>
<a class="adv-item" href="/app/usage"><div class="l">用量与账单</div><span>›</span></a>
<a class="adv-item" href="/app/llm-models"><div class="l">LLM 模型</div><span>›</span></a>
<a class="adv-item" href="/app/settings"><div class="l">账号 / API Key</div><span>›</span></a>
<a class="adv-item" href="/debug/devices"><div class="l">调试 · 设备</div><span>›</span></a>
<a class="adv-item" href="/debug/tts"><div class="l">调试 · TTS</div><span>›</span></a>
<a class="adv-item" href="/debug/llm"><div class="l">调试 · LLM</div><span>›</span></a>
<a class="adv-item" href="/debug/simulation"><div class="l">调试 · 模拟</div><span>›</span></a>
<p class="lead" style="margin-top:16px">＊ 这些都是既有控制台页面，功能不变，只是默认收起。</p>
{% endblock %}
```

在 `theme_2c.css` 末尾补 `a.adv-item{text-decoration:none}`（原型 `.adv-item` 是 div）。

- [ ] **Step 2: 手动验收**：`/advanced` 列出链接，点击进入既有页面且功能正常。

- [ ] **Step 3: Commit**

```bash
git add src/deskbot_server/web/templates/app2c/advanced.html src/deskbot_server/web/static/theme_2c.css
git commit -m "feat(web2c): advanced hub linking existing admin/debug pages"
```

---

### Task 10: 回归 — 既有页面与测试不受影响

- [ ] **Step 1: 跑全量测试**

Run: `cd service/deskbot-server && python -m pytest -q`
Expected: 全部 PASS（既有用例 + 新增 `test_app2c_pages.py`）

- [ ] **Step 2: 手动回归**：旧入口 `/app`、`/debug/*` 仍可访问、行为不变。

- [ ] **Step 3: Commit（如有微调）**

```bash
git add -A && git commit -m "test(web2c): full suite green after 2C shell"
```

---

## Phase 2 — 情绪→场景映射（可选）

> 仅当确认需要"给情绪指定表情场景"的持久化时实施。这是本计划唯一的新增后端。

### Task 11: emotion_expr_map_store（TDD）

**Files:**
- Create: `src/deskbot_server/emotion_expr_map_store.py`
- Create: `src/deskbot_server/constants.py` 中新增常量 `EMOTION_EXPR_MAP_FILE`（若 `constants.py` 已集中管理文件名）
- Test: `tests/test_emotion_expr_map_store.py`

- [ ] **Step 1: 写失败测试**

```python
# tests/test_emotion_expr_map_store.py
from __future__ import annotations

import tempfile
from pathlib import Path

import pytest

@pytest.fixture()
def map_file(monkeypatch):
    with tempfile.TemporaryDirectory() as tmp:
        path = Path(tmp) / "emotion_expr_map.json"
        monkeypatch.setattr(
            "deskbot_server.emotion_expr_map_store.EMOTION_EXPR_MAP_FILE",
            str(path),
        )
        yield path

def test_load_defaults_empty(map_file):
    from deskbot_server.emotion_expr_map_store import load_emotion_expr_map

    assert load_emotion_expr_map(device_id=None) == {}

def test_save_then_load_roundtrip(map_file):
    from deskbot_server.emotion_expr_map_store import (
        load_emotion_expr_map,
        save_emotion_expr_map,
    )

    save_emotion_expr_map({"happy": "smile", "sad": "sad"}, device_id=None)
    assert load_emotion_expr_map(device_id=None) == {"happy": "smile", "sad": "sad"}

def test_save_rejects_non_string_values(map_file):
    from deskbot_server.emotion_expr_map_store import save_emotion_expr_map

    with pytest.raises(ValueError):
        save_emotion_expr_map({"happy": 123}, device_id=None)
```

- [ ] **Step 2: 运行确认失败**

Run: `cd service/deskbot-server && python -m pytest tests/test_emotion_expr_map_store.py -q`
Expected: FAIL（模块不存在）

- [ ] **Step 3: 实现 store**

```python
# src/deskbot_server/emotion_expr_map_store.py
from __future__ import annotations

import json
import os
from typing import Optional

from deskbot_server.device_data import resolve_json_path

EMOTION_EXPR_MAP_FILE = "emotion_expr_map.json"

def _normalize(raw: object) -> dict[str, str]:
    if not isinstance(raw, dict):
        raise ValueError("emotion map must be an object")
    out: dict[str, str] = {}
    for k, v in raw.items():
        if not isinstance(v, str):
            raise ValueError(f"scene for emotion {k!r} must be a string")
        out[str(k)] = v
    return out

def load_emotion_expr_map(*, device_id: Optional[str] = None) -> dict[str, str]:
    path = resolve_json_path(EMOTION_EXPR_MAP_FILE, device_id)
    if not os.path.isfile(path):
        return {}
    with open(path, encoding="utf-8") as f:
        return _normalize(json.load(f))

def save_emotion_expr_map(
    mapping: dict[str, str], *, device_id: Optional[str] = None
) -> dict[str, str]:
    norm = _normalize(mapping)
    path = resolve_json_path(EMOTION_EXPR_MAP_FILE, device_id)
    os.makedirs(os.path.dirname(path) or ".", exist_ok=True)
    with open(path, "w", encoding="utf-8") as f:
        json.dump(norm, f, ensure_ascii=False, indent=2)
        f.write("\n")
    return norm
```

- [ ] **Step 4: 运行确认通过**

Run: `cd service/deskbot-server && python -m pytest tests/test_emotion_expr_map_store.py -q`
Expected: PASS（3 用例）

- [ ] **Step 5: Commit**

```bash
git add src/deskbot_server/emotion_expr_map_store.py tests/test_emotion_expr_map_store.py
git commit -m "feat(expr-map): per-device emotion->scene map store with tests"
```

---

### Task 12: 映射接口 GET/POST /api/emotion_expr_map（TDD）

**Files:**
- Modify: `src/deskbot_server/web/blueprints/app2c_bp.py`
- Test: `tests/test_emotion_expr_map_api.py`

- [ ] **Step 1: 写失败测试**

```python
# tests/test_emotion_expr_map_api.py
from __future__ import annotations

import tempfile
from pathlib import Path

import pytest

@pytest.fixture()
def temp_db(monkeypatch):
    with tempfile.TemporaryDirectory() as tmp:
        monkeypatch.setenv("DESKBOT_DB_PATH", str(Path(tmp) / "t.db"))
        from deskbot_server.db import init_database
        from deskbot_server.db.engine import init_engine, reset_engine

        reset_engine()
        init_engine(Path(tmp) / "t.db")
        init_database()
        yield

def _client():
    from deskbot_server.auth.device_service import bind_device
    from deskbot_server.auth.service import create_user
    from deskbot_server.web.app import create_app

    user = create_user("map@example.com", "password1234")
    bind_device(user.id, "deskbot_map")
    app = create_app()
    c = app.test_client()
    c.post("/login", data={"email": "map@example.com", "password": "password1234"})
    c.post("/app/api/devices/select", json={"device_id": "deskbot_map"})
    return c

def test_get_empty_then_post_roundtrip(temp_db):
    c = _client()
    g = c.get("/api/emotion_expr_map").get_json()
    assert g["ok"] is True and g["map"] == {}

    p = c.post("/api/emotion_expr_map", json={"map": {"happy": "smile"}}).get_json()
    assert p["ok"] is True

    g2 = c.get("/api/emotion_expr_map").get_json()
    assert g2["map"] == {"happy": "smile"}
```

- [ ] **Step 2: 运行确认失败**

Run: `cd service/deskbot-server && python -m pytest tests/test_emotion_expr_map_api.py -q`
Expected: FAIL（路由不存在 → 404）

- [ ] **Step 3: 实现接口**（追加到 `app2c_bp.py`）

```python
from flask import jsonify, request
from flask_login import current_user

from deskbot_server.auth.device_service import user_owns_device
from deskbot_server.emotion_expr_map_store import (
    load_emotion_expr_map,
    save_emotion_expr_map,
)
from deskbot_server.web.session_device import get_current_device_id

def _owned_device_or_error():
    device_id = (request.args.get("device_id") or get_current_device_id() or "").strip()
    if not device_id:
        return None, (jsonify({"ok": False, "error": "请先选择设备"}), 400)
    if not user_owns_device(current_user.id, device_id):
        return None, (jsonify({"ok": False, "error": "设备不属于当前账号"}), 403)
    return device_id, None

@bp.get("/api/emotion_expr_map")
@login_required
def emotion_expr_map_get():
    device_id, err = _owned_device_or_error()
    if err:
        return err
    return jsonify({"ok": True, "device_id": device_id, "map": load_emotion_expr_map(device_id=device_id)})

@bp.post("/api/emotion_expr_map")
@login_required
def emotion_expr_map_post():
    device_id, err = _owned_device_or_error()
    if err:
        return err
    payload = request.get_json(silent=True) or {}
    mapping = payload.get("map")
    if not isinstance(mapping, dict):
        return jsonify({"ok": False, "error": "map 必须是对象"}), 400
    try:
        saved = save_emotion_expr_map(mapping, device_id=device_id)
    except ValueError as exc:
        return jsonify({"ok": False, "error": str(exc)}), 400
    return jsonify({"ok": True, "map": saved})
```

> 说明：`device_id` 来自 query 或 session 当前设备；POST 用 JSON body（无 query 时回退 session）。POST 路径下 `request.args.get('device_id')` 为空将回退 `get_current_device_id()`，测试已 `select` 当前设备。

- [ ] **Step 4: 运行确认通过**

Run: `cd service/deskbot-server && python -m pytest tests/test_emotion_expr_map_api.py -q`
Expected: PASS

- [ ] **Step 5: Commit**

```bash
git add src/deskbot_server/web/blueprints/app2c_bp.py tests/test_emotion_expr_map_api.py
git commit -m "feat(expr-map): GET/POST /api/emotion_expr_map endpoints with tests"
```

---

### Task 13: 表情页接入情绪映射

**Files:**
- Modify: `src/deskbot_server/web/templates/app2c/expr.html`

- [ ] **Step 1: 在表情页加情绪→场景下拉**

在 Task 6 的 `expr.html` 内容区追加一段「情绪 → 表情」映射区（参考原型 `#emoMap` 与 `.maprow`），并在 Vue 中：
- `data` 增加 `emotions:[['happy','开心'],['surprised','惊讶'],['thinking','思考'],['sleepy','困'],['idle','待机']]` 与 `map:{}`。
- `mounted`/`load()` 末尾 `this.map = (await (await fetch('/api/emotion_expr_map')).json()).map || {}`。
- 每行一个 `<select v-model="map[key]">`，选项为 `scenes` 的 `name`（显示 `title`）。
- `save()` 末尾追加：`await fetch('/api/emotion_expr_map',{method:'POST',headers:{'Content-Type':'application/json'},body:JSON.stringify({map:this.map})})`。

完整片段：

```html
<div class="blocktitle">情绪 → 表情</div>
<div class="maprow" v-for="[k,label] in emotions" :key="k">
  <div class="lab">[[ label ]]</div>
  <select v-model="map[k]">
    <option value="">（不指定）</option>
    <option v-for="s in scenes" :key="s.name" :value="s.name">[[ s.title || s.name ]]</option>
  </select>
</div>
```

```javascript
// data(): 追加
emotions:[['happy','开心'],['surprised','惊讶'],['thinking','思考'],['sleepy','困'],['idle','待机']],
map:{},
// load() 末尾追加
this.map = ((await (await fetch('/api/emotion_expr_map'+(this.deviceId?('?device_id='+encodeURIComponent(this.deviceId)):''))).json()).map) || {};
// save() 末尾追加（在原 face_expr_scenes 保存之后）
await fetch('/api/emotion_expr_map',{method:'POST',headers:{'Content-Type':'application/json'},
  body:JSON.stringify({device_id:this.deviceId, map:this.map})});
```

- [ ] **Step 2: 手动验收**：表情页可给情绪选场景、保存后刷新仍在；`GET /api/emotion_expr_map` 复核。

- [ ] **Step 3: 跑全量测试**

Run: `cd service/deskbot-server && python -m pytest -q`
Expected: 全绿

- [ ] **Step 4: Commit**

```bash
git add src/deskbot_server/web/templates/app2c/expr.html
git commit -m "feat(web2c): wire emotion->scene mapping into expression page"
```

---

## 落地后说明（运行）

启动（既有方式）：`cd service && ./start.sh`，或单独 web：`cd service/deskbot-server && python -m deskbot_server.web`。
登录 `http://<IP>:5050/login` 后自动落地 `/home`。开发者入口仍在 `/app`、`/debug/*`，并由 `/advanced` 聚合。

## 接口形状（均已实测确认）
- `GET /api/face_expr_scenes` → 场景在 `config` 键下；POST body `{device_id, scenes:[…]}` 兼容。
- `GET /app/api/scheduled-tasks` → `{ok, tasks:[{id, description, cron_expr, next_run_at, enabled, …}]}`。
- `GET /app/api/face-profiles` → `{ok, profiles:[{person_id, name, …}]}`。
- `GET /api/doubao_tts/speakers` / `config` / `synthesize`、`/app/api/memories|devices` 均已在上文任务按真实返回接线。

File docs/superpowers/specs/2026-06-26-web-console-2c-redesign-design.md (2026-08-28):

# Web 控制台 2C 化改造 · 设计文档

> **状态：历史设计稿（2026-06-26）。** 文中「Flask + Jinja」与路径 `service/deskbot-server/` 已过时；实现栈为 **FastAPI**，代码在 `service/src/deskbot_server/`。请以 [service/README.md](../../../service/README.md) 与 [ARCHITECTURE.md](../../../service/docs/ARCHITECTURE.md) 为准。

- 日期：2026-06-26
- 范围：当时计划改造 Web 控制台（原稿写 Flask；现已 FastAPI）
- 性质：交互层（前端 + 薄接口）重构，**不改动核心管线、协议、固件、调度、识别能力**

## 1. 背景与目标

现有 Web 控制台（端口 5050）是面向开发者/管理员的形态：侧边栏平铺 8+ 个功能页（dashboard / devices / scheduled-tasks / face-profiles / memories / llm-models / usage / account），外加 6 个 debug 调试页。术语和信息密度都偏工程向。

目标：把它改造成一个**面向普通用户（2C）的配套 App**——机器人本体仍是 ESP32 实体设备，网页是它的消费级配套（不另做原生客户端）。要求：

1. 所有复杂配置默认隐藏。
2. 把 **表情定制** 和 **声音定制** 做成两个核心可玩功能（产品主角）。
3. 复用现有后端能力，不改核心功能逻辑。

## 2. 非目标（明确不做）

- 不改动 ASR / LLM / TTS 管线、pb 协议、设备固件、定时调度、人脸识别等核心逻辑。
- 不做 **语速 / 音调** 调节（豆包 TTS 当前仅 `speaker` + `sample_rate`，无 speed/pitch）。
- 不做 **声音克隆**（后端无克隆能力）。
- 不删除任何现有功能；用量/账单、API Key、LLM 模型、debug 页全部保留，仅降权隐藏。
- 不引入新的前端框架（继续 Flask + Jinja + 内联 Vue）。

## 3. 现有能力盘点（设计的事实依据）

### 已有完整 JSON 接口（纯前端即可重新包装）
- 设备：`GET/POST /app/api/devices`、`POST /app/api/devices/select`、`DELETE /app/api/devices/<id>`
- 记忆：`GET/POST /app/api/memories`、`GET/PUT/PATCH/DELETE /app/api/memories/<id>`
- 提醒（定时任务）：`GET /app/api/scheduled-tasks`、`DELETE /app/api/scheduled-tasks/<id>`
- 人脸：`GET /app/api/face-profiles`、`DELETE /app/api/face-profiles/<person_id>`
- 用量：`/app/usage`（页面级）

### 已有 Web JSON 接口（实测，可直接被前端复用 —— 修正：并非"缺接口"）
两个英雄功能的后端接口其实**已存在于 `debug_bp`**，无需新增：
- 声音：
  - `GET /api/doubao_tts/speakers` → 音色画廊（`{ok, speakers:[{label,id,scene,resource_id,...}]}`）。
  - `GET /api/doubao_tts/config` / `POST /api/doubao_tts/config` → 读/设当前音色（POST 经 `save_doubao_tts_env` 写 `DOUBAO_TTS_SPEAKER` 并刷新进程环境，**全局生效**）。
  - `POST /api/doubao_tts/synthesize` → 试听，返回 `wav_base64`（浏览器可直接播放）。
- 表情：
  - `GET /api/face_expr_scenes?device_id=` → 按设备读场景（`load_face_expr_scenes_file`，缺省自动 seed `builtin_emotion_scenes()`）。
  - `POST /api/face_expr_scenes` → 按设备写场景（`save_face_expr_scenes_file`）。
- 场景数据形状：`{name:[a-z0-9_], title, frames:[{ms, elements:{mouth,nose,eye_l,eye_r,extra}}]}`。
- 音量：已支持（LLM JSON `volume` 字段 + 设备播放音量）。

> 影响：原计划的"4 个新薄接口"**作废**。改造主体变为**纯前端**（消费级外壳 + 页面，调用上述既有接口）。
> 唯一可能新增的后端 = 一个极小的 **per-device 情绪→场景映射 store**（见 §7.2 / §5.1，列为可选 Phase 2）。

## 4. 信息架构（三层）

> 形态：**桌面 Web App**（非移动端）。采用左侧固定导航栏 + 右侧内容区的经典 Web 布局；
> 一级导航项 = 家 / 表情 / 声音 / 它记得的事 / 提醒 / 认识的人 / 我的设备，底部一个降权的「⚙️ 高级」。

### ① 首页「家」（Home）
进入即见机器人：
- 大表情预览区（复用设备 284×240 画面渲染）。
- 状态条：在线/离线、当前音色名、当前性格/表情、"记得 N 件事 / N 个提醒"。
- 两张 C 位大卡片入口：🎭 捏表情 · 🔊 调声音。

### ② 中层功能
- 英雄功能（独立全屏体验）：🎭 表情、🔊 声音。
- 生活化功能（卡片入口，二级）：🧠 它记得的事、⏰ 提醒、👤 认识的人、📱 我的设备。

### ③ 底层「⚙️ 高级」
置于页脚或头像菜单，默认折叠、视觉降权。把现有管理页 **原样搬入** `/advanced/*`：用量/账单、API Key、LLM 模型、所有 debug 调试页。功能不删，普通用户不可见。

> 核心手法：不删功能，只**重新分层 + 重新命名 + 重新叙事**。
> face-profiles → 认识的人；memories → 它记得的事；scheduled-tasks → 提醒。

## 5. 英雄功能详细设计

### 5.1 🎭 表情定制
背靠 `face_expr_scenes_store`（per-device）。

- **皮肤打底**：顶部一排预设"面孔风格"缩略图（来自 `builtin_emotion_scenes()` / 现有场景），点击整套切换，右侧大图实时预览。
- **情绪挂表情**：情绪清单（开心 / 惊讶 / 思考 / 困 / 待机…），每个情绪一个下拉，映射到某个表情场景（即"情绪-表情映射"）。
- **所见即所得**：选中即在 284×240 大脸上播放该场景动画（纯前端用现有动画数据渲染）。
- **保存**：调薄接口写回 per-device 表情/映射数据。

### 5.2 🔊 声音定制
背靠 `doubao_tts_speakers.json` + `tts/speakers.py`。

- **音色画廊**：卡片网格列出豆包音色，按 `scene` 分组（客服 / 教育 / 有声阅读 / 视频配音…）。
- **试听**：每张卡 ▶️ 试听，走现有 TTS 合成路径念一句固定示例（不新增合成能力）。
- **设为当前音色**：写当前 speaker。
- **音量**：滑杆（后端已支持）。
- 不含语速/音调/克隆。

## 6. 生活化功能（纯前端，零后端改动）

| 现有 | 改名 | 交互 | 背靠接口 |
|---|---|---|---|
| memories | 🧠 它记得的事 | 便利贴式记忆卡，增/改/删 | `/app/api/memories`（已全有） |
| scheduled-tasks | ⏰ 提醒 | 时间轴列表，可删 | `/app/api/scheduled-tasks`（已有列/删） |
| face-profiles | 👤 认识的人 | 头像网格 + 名字，改名/删 | `/app/api/face-profiles`（已有列/删） |
| devices | 📱 我的设备 | 设备卡 + 在线灯 + 绑定向导 | `/app/api/devices`（已全有） |

dashboard 保留但瘦身，并入首页"家"页的状态条。

## 7. 技术落地

### 7.1 前端
- 继续 Flask + Jinja + 内联 Vue + `theme.css`，不引新框架。
- 新增消费级布局母版 `base_2c.html` 与新主题 `theme_2c.css`。
- 现有 `base.html` + 全部管理/调试页**原封不动**搬到 `/advanced/*` 作为"高级"区。
- 图标统一用 **Lucide**（ISC ≈ MIT 许可，24px 栅格 / 2px 圆角描边）；不使用 emoji 作为导航或卡片标签。可经包管理器引入或内联 SVG，保持全站一套图标语言。

### 7.2 后端改动（修正后：Phase 1 零新增，Phase 2 仅一个极小 store）

**Phase 1 — 零新增后端**：声音/表情/记忆/提醒/人/设备全部调用既有 JSON 接口（见 §3）。
唯一后端层面的改动是把**登录后落地页**指向新的消费首页（一处 redirect）。

**Phase 2（可选）— 情绪→场景映射**：现有 `face_expr_scenes_store` 存的是"场景列表"，不含"情绪→场景"映射。
若要实现 §5.1 的情绪映射持久化，新增一个极小 per-device store：

| 新增 | 作用 | 复用机制 |
|---|---|---|
| `emotion_expr_map_store.py` | 读/写 per-device `emotion_expr_map.json`（`{emotion_key: scene_name}`） | `device_data.resolve_json_path`（与 `face_expr_scenes_store` 同一 per-device 机制） |
| `GET/POST /api/emotion_expr_map` | 前端读写映射 | 上述 store |

- 试听复用既有 `POST /api/doubao_tts/synthesize`，不新增能力。
- 新增接口沿用现有 `before_request` 鉴权与 per-device 约定。

### 7.3 明确不动
ASR / LLM / TTS 管线、pb 协议、设备固件、定时调度、人脸识别。

## 8. 验收标准

1. 普通用户登录后首屏即见机器人 + 表情/声音两个入口，看不到任何 debug/API Key/模型/用量术语。
2. 表情：能切换皮肤、给至少 4 种情绪指定表情场景、实时预览、保存后通过 `GET /app/api/expressions` 可读回。
3. 声音：能浏览按场景分组的音色画廊、试听、设为当前音色（`POST /app/api/voice/active` 生效）、调音量。
4. 记忆/提醒/认识的人/设备四项均以新叙事呈现，且 CRUD 行为与原接口一致。
5. `/advanced/*` 下原有全部管理/调试功能可访问、行为不变。
6. 核心管线/协议/固件无任何代码改动。

## 9. 风险与依赖

- 表情实时预览需在浏览器用现有动画数据渲染 284×240 画面；若现有 pb/动画数据格式不便于前端直接渲染，预览可降级为"静态首帧 + 场景名"，不阻塞保存能力。
- 试听依赖 TTS 服务在线；离线时按钮置灰并提示。
- 设当前音色的写入位置（env vs config.yaml）需在实现期确认生效路径，确保与设备实际取用一致。

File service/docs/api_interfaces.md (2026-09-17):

# 接口清单

更新时间：2026-08-29

本文按当前代码实现整理所有对外接口，覆盖 Web 控制台与 deskbot 设备服务。重点列 HTTP / WebSocket 路由、鉴权、主要参数与返回用途；ESP32 pb 字段细节见 [esp32_pb_protocol.md](./esp32_pb_protocol.md)。固件工具链见 [../../hardware/README.md](../../hardware/README.md)。

## 服务与端口

| 服务 | 默认地址 | 实现位置 | 说明 |
|---|---|---|---|
| Web 控制台 | `http://<host>:9000` | `deskbot_server.web` | FastAPI 页面、用户登录、设备/记忆/模型管理、调试页、代理到设备服务 |
| deskbot 设备服务 | `ws://<host>:9000` / `http://<host>:9000` | `deskbot_server.controller` / `deskbot_server.ws` | ESP32 主链路、调试订阅、设备下发、轻量 HTTP API |

## 鉴权约定

### Web 控制台 `:9000`

| 范围 | 鉴权 |
|---|---|
| `/`、`/login`、`/register`、`/health`、`/static/*` | 公开 |
| 其它页面 | 需要会话登录态；未登录重定向到 `/login` |
| `/api/*` | 需要会话登录态；未登录返回 `401 {"ok": false, "error": "unauthorized"}` |
| `/proxy/deskbot/*` | 需要登录态，并按当前用户绑定设备过滤/补全 `device_id` |

### deskbot 设备服务 `:9000`

| 范围 | 鉴权 |
|---|---|
| `GET /health` | 公开 |
| `/api/*` | Web 会话或 `debug_token`；无 user_id 时匿名放行 |
| `/asr_chat` | 仅需 `device_id`（无 API Key / PIN）；含语音与 `camera_frame` |
| `/device_pipeline` 生产者 | 仅需 `device_id` |
| `/device_pipeline` 订阅者、`/camera_view` | Web 控制台签发的 `debug_token` + 设备归属 |

常见错误：设备缺 `device_id` 为 WS close `1008 device_id_required`；未登录访问 Web API 为 `401`；操作未绑定设备为 `403 forbidden_device`。

## Web 控制台页面与表单 `:9000`

### 公开与账号

| 方法 | 路径 | 用途 | 主要输入 |
|---|---|---|---|
| GET | `/` | 站点首页；已登录时跳转 `/home` | - |
| GET | `/login` | 登录页 | `next` query |
| POST | `/login` | 登录提交 | form: `email`, `password`, `next` |
| GET | `/register` | 注册页 | - |
| POST | `/register` | 注册提交并登录 | form: `email`, `password`, `confirm_password` |
| POST | `/logout` | 退出登录 | - |
| GET | `/health` | Web 控制台健康检查 | 返回纯文本 `ok` |

### 2C 用户页面

| 方法 | 路径 | 用途 |
|---|---|---|
| GET | `/home` | 2C 首页 |
| GET | `/expr` | 表情设置/入口 |
| GET | `/my/memories` | 我的记忆 |
| GET | `/my/reminders` | 我的提醒 |
| GET | `/my/people` | 我的人物/人脸 |
| GET | `/my/devices` | 我的设备 |
| GET | `/advanced` | 账户设置 |

### 管理后台页面

| 方法 | 路径 | 用途 |
|---|---|---|
| GET | `/app/` | 工作台 |
| GET | `/app/devices` | 设备管理 |
| GET | `/app/scheduled-tasks` | 定时任务列表 |
| GET | `/app/face-profiles` | 人脸档案 |
| GET | `/app/memories` | 长期记忆 |
| GET | `/app/llm-models` | LLM 模型配置 |
| GET | `/app/usage` | 用量看板 |
| GET | `/app/settings` | 账号设置（资料、密码、LLM 模型配置） |
| POST | `/app/settings/profile` | 更新显示名 | form: `display_name` |
| POST | `/app/settings/password` | 修改密码 | form: `old_password`, `new_password`, `confirm_password` |

### 调试页面

| 方法 | 路径 | 用途 |
|---|---|---|
| GET | `/debug/devices` | 在线设备、流水线、表情/舵机调试 |
| GET | `/debug/tts` | 豆包 TTS 调试 |
| GET | `/debug/llm` | LLM 试聊与 system prompt |
| GET | `/debug/simulation` | 模拟对话/显示调试 |

## Web 控制台 JSON API `:9000`

### 2C 账户设置

| 方法 | 路径 | 用途 | 主要输入 |
|---|---|---|---|
| GET | `/api/advanced` | 汇总当前用户资料 | - |
| PATCH | `/api/advanced/profile` | 更新显示名 | JSON: `display_name` |
| POST | `/api/advanced/password` | 修改密码 | JSON: `old_password`, `new_password`, `confirm_password` |
| GET | `/api/emotion_expr_map` | 读取情绪到表情映射 | query: `device_id` 可选，默认当前设备 |
| POST | `/api/emotion_expr_map` | 保存情绪到表情映射 | JSON: `map` |

### 管理后台数据 API

| 方法 | 路径 | 用途 | 主要输入 |
|---|---|---|---|
| GET | `/app/api/devices` | 当前用户绑定设备列表 | - |
| POST | `/app/api/devices` | 绑定设备并设为当前设备 | JSON/form: `device_id`, JSON: `display_name` 可选 |
| POST | `/app/api/devices/select` | 切换当前设备；空 `device_id` 清空选择 | JSON: `device_id` |
| DELETE | `/app/api/devices/{device_id}` | 解绑设备 | path: `device_id` |
| DELETE | `/app/api/devices/{device_id}/data` | 清除设备全部云端数据（保留绑定与设备级设置：provider/param/volume/quest_id） | path: `device_id` |
| GET | `/app/api/scheduled-tasks` | 查询设备定时任务 | query: `device_id` 可选，默认当前设备 |
| DELETE | `/app/api/scheduled-tasks/{task_id}` | 删除定时任务 | path: `task_id`, query: `device_id` 可选 |
| GET | `/app/api/face-profiles` | 查询人脸档案摘要 | query: `device_id` 可选 |
| PUT/PATCH | `/app/api/face-profiles/{person_id}` | 更新人脸名称 | JSON: `name`, query: `device_id` 可选 |
| DELETE | `/app/api/face-profiles/{person_id}` | 删除人脸档案 | path: `person_id`, query: `device_id` 可选 |
| GET | `/app/api/memories` | 查询长期记忆 | query: `device_id` 可选 |
| POST | `/app/api/memories` | 新增长期记忆 | JSON/form: `text` |
| GET | `/app/api/memories/{entry_id}` | 查询单条记忆 | path: `entry_id` |
| PUT/PATCH | `/app/api/memories/{entry_id}` | 更新记忆文本 | JSON: `text` |
| DELETE | `/app/api/memories/{entry_id}` | 删除记忆 | path: `entry_id` |
| GET | `/app/api/llm-models` | 查询设备 LLM 模型列表与当前生效配置 | query: `device_id` 可选 |
| POST | `/app/api/llm-models` | 新增设备 LLM 模型 | JSON: `name`, `model_name`, `protocol`, `base_url`, `api_key` |
| PUT | `/app/api/llm-models/{model_id}` | 更新设备 LLM 模型 | JSON: `name`, `model_name`, `protocol`, `base_url`, `api_key` 可选 |
| DELETE | `/app/api/llm-models/{model_id}` | 删除设备 LLM 模型 | path: `model_id` |
| POST | `/app/api/llm-models/select` | 选择/清空当前 LLM 模型 | JSON: `model_id`，可为 `null` |

这些接口均会校验当前用户是否拥有目标 `device_id`。未选设备返回 `400`，设备不属于当前用户返回 `403`。

### 机器人设置 API（机器人配置页；TTS 为设备级配置）

TTS provider / 音色 / 凭证已移至设备级（devices 表 `tts_provider` / `tts_param`），
`config.yaml` 不再承载 TTS 配置，`/app/api/tts/*` 全局端点（含 preview 配额）已移除。
豆包 API Key 由各设备自配（`tts_param.doubao.api_key`），服务器不持有公共凭证。

| 方法 | 路径 | 用途 | 主要输入 |
|---|---|---|---|
| GET | `/api/robot-settings` | 能力状态（ASR/LLM/TTS/人脸 + 服务快照 + env 覆盖） | session: `device_id` |
| GET | `/api/robot-settings/llm/config-info` | LLM 配置对话框元信息：ark 当前值（api_key 掩码）、siliconflow 模型预设 + 服务端密钥状态、本地模型只读固定端点 | query: `provider` |
| POST | `/api/robot-settings/llm/config` | 保存设备级 LLM 配置到 `devices.llm_param[provider]`（不写 `.env` / `config.yaml`）：ark 存 `api_key`/`model_name`/`base_url`（掩码/空不覆盖），siliconflow **只存 `model_name`**——其密钥是服务端公共凭证（`.env` `SILICONFLOW_API_KEY`），payload 里的 `api_key` 会被字段白名单丢弃 | JSON: `provider`, `api_key`, `model_name`, `base_url` |
| POST | `/api/robot-settings/llm/test` | LLM 试聊（临时 config 不落盘；overrides 表单覆盖优先，本地模型免 Key；siliconflow 不要求当前设备，只需要模型） | JSON: `provider`, `text`, `overrides`? |
| POST | `/api/robot-settings/tts` | 切换 TTS provider（写 device 表 tts_provider，立即生效） | JSON: `provider` |
| GET | `/api/robot-settings/tts/config-info` | TTS 配置对话框元信息：音色列表 + 当前设备参数（api_key 掩码，设备 tts_param 优先回落 .env） | session: `device_id` |
| POST | `/api/robot-settings/tts/config` | 保存设备级 TTS 参数到 tts_param（JSON：`{"moss": {"demo_id"}, "doubao": {api_key, speaker, resource_id, model, ws_url, sample_rate}}`；空值/掩码按 payload > 设备 > .env 回填） | session: `device_id` |
| POST | `/api/robot-settings/tts/clear-device-override` | 重置设备 TTS：provider=moss-tts-nano + tts_param 清空 | session: `device_id` |
| GET | `/api/robot-settings/tts/test-info` | 测试对话框元信息（兼容；当前音色设备级） | session: `device_id` |
| POST | `/api/robot-settings/tts/test` | 合成试听（不落盘；overrides / voice_id 临时覆盖，设备参数优先） | JSON: `provider`, `text`, `voice_id`?, `overrides`? |

### Web 调试 API

| 方法 | 路径 | 用途 | 主要输入 |
|---|---|---|---|
| GET | `/api/debug/ws_token` | 为已登录用户签发调试 WebSocket `debug_token` | - |
| GET | `/api/doubao_tts/speakers` | 豆包 TTS 说话人预设 | - |
| GET | `/api/doubao_tts/config` | 读取豆包 TTS 配置，密钥脱敏 | - |
| POST | `/api/doubao_tts/config` | 保存豆包 TTS 配置 | JSON: `api_key`, `speaker`, `resource_id`, `model`, `ws_url`, `sample_rate`, `audio_format` |
| POST | `/api/doubao_tts/synthesize` | 豆包 TTS 合成并返回 WAV base64 | JSON: `text`，可带临时 TTS 配置 |
| GET | `/api/llm/system_prompt` | 读取设备 LLM system prompt | query/body/session: `device_id` |
| POST | `/api/llm/system_prompt` | 保存设备 LLM system prompt | JSON: `system_prompt` 或 `content`, `device_id` 可选 |
| POST | `/api/llm/chat` | 调试 LLM 对话，不直接走设备 ASR | JSON: `text`, `history`, `system_prompt`, `temperature`, `device_id`, `device_context` |
| GET | `/api/servo_config` | 读取舵机配置 | query/session: `device_id` |
| POST | `/api/servo_config` | 保存舵机配置 | JSON: servo 文档 |
| GET | `/api/camera_face_config` | 读取相机人脸检测配置 | query/session: `device_id` |
| POST | `/api/camera_face_config` | 保存相机人脸检测配置 | JSON: camera face 文档 |
| GET | `/api/face_profiles` | 读取人脸档案原始文件 | query/session: `device_id` |
| POST | `/api/face_profiles/register` | 绑定当前检测到的人脸为档案 | JSON: `device_id`, `face_id`, `name` |
| GET | `/api/user_memory` | 读取设备长期记忆原始列表 | query/session: `device_id` |
| POST | `/api/user_memory` | 新增长期记忆 | JSON: `text`, `device_id` 可选 |
| DELETE | `/api/user_memory/{entry_id}` | 删除长期记忆 | path: `entry_id`, query/session: `device_id` |
| GET | `/api/face_mouth_by_phoneme` | 读取音素口型组表 | query/session: `device_id` |
| POST | `/api/face_mouth_by_phoneme` | 保存音素口型组表 | JSON: 组表数组或文档 |
| GET | `/api/face_expr_scenes` | 读取表情场景配置 | query/session: `device_id` |
| POST | `/api/face_expr_scenes` | 保存表情场景配置 | JSON: 场景数组 |
| GET | `/api/scene_playbooks` | 读取场景 playbook 配置 | query/session: `device_id` |
| POST | `/api/scene_playbooks` | 保存场景 playbook 配置 | JSON: playbook 数组 |
| GET | `/api/health` | 检查 deskbot-server 与 TTS 端口是否可连 | - |

### 代理 API

| 方法 | 路径 | 用途 |
|---|---|---|
| GET/POST/PUT/DELETE/OPTIONS | `/proxy/deskbot/{subpath}` | 登录用户访问 `:9000` HTTP API 的代理入口；会过滤 `/api/devices`，并对需要设备的路径校验/补全当前 `device_id` |

代理会将请求转发到 `deskbot_upstream_base()`。当前设备相关的代理路径包括 `/api/device_servo`、`/api/device_tts`、`/api/device_pb_scene`、`/api/device_pb_anim`、`/api/device_pb_expr_scene`、`/api/device_pb_scenes`、`/api/scene_playbook/run`。

## deskbot WebSocket `:9000`

### `/asr_chat`

生产设备主链路。默认 URL：

```text
ws://<host>:9000/asr_chat?device_id=<id>
```

`device_id` 别名：`device_id`、`deviceid`、`device`、`id`。连接成功后服务端发送：

```json
{"type": "ready", "device_id": "<id>"}
```

设备上行消息：

| 方向 | 消息 | binary | 用途 |
|---|---|---|---|
| 设备 -> 服务端 | `{"type":"audio","codec":"opus|pcm16","next_bin_len":N}` | 下一帧为音频 | 输入语音；也兼容 `data` base64 或裸 binary |
| 设备 -> 服务端 | `{"type":"flush"}` | 无 | 结束当前语音段，触发 ASR/LLM/TTS |
| 设备 -> 服务端 | `{"type":"camera_frame","codec":"jpeg","next_bin_len":N,"seq":...}` | 下一帧为 JPEG | 上传画面用于人脸检测、预览、跟随 |
| 设备 -> 服务端 | `{"type":"pb_ack", ...}` | 无 | 播放回压与状态上报；会进入设备流水线订阅 |
| 设备 -> 服务端 | `{"type":"user_text","text":"..."}` | 无 | 调试：跳过 ASR，直接进入对话 |
| 设备 -> 服务端 | `{"type":"ping"}` | 无 | 保活；非 pb-only 模式回 `pong` |

服务端下行消息：

| 消息 | binary | 用途 |
|---|---|---|
| `pb_start` / `pb_chunk` / `pb_end` | 可选，取决于 `audio.next_bin_len` | 多片 pb 下发，含 PCM、表情、舵机 |
| `pb_single` | 可选 | 单片 pb 下发 |
| `face_info` | 无 | 仅 `send_face_info_to_asr_chat=true` 且非 pb-only 时可能下发 |
| `ready` / `pong` / 错误类 JSON | 无 | 握手、保活、异常提示 |

默认 `asr_chat_device_pb_only: true`，设备端应只依赖 `pb_*` + PCM。pb wire 规则见 [esp32_pb_protocol.md](./esp32_pb_protocol.md)。

### `/camera_view`

调试 JPEG 预览订阅。URL：

```text
ws://<host>:9000/camera_view?device_id=<id>&debug_token=<token>
```

| 方向 | 消息 | 用途 |
|---|---|---|
| 服务端 -> 客户端 | `{"type":"ready","channel":"camera_view","device_filter":"...","expects":"binary JPEG frames preceded by camera_frame meta"}` | 订阅就绪 |
| 服务端 -> 客户端 | `{"type":"camera_frame", ...}` + 下一帧 JPEG binary | 最新相机帧与检测元数据 |
| 客户端 -> 服务端 | `{"type":"ping"}` | 服务端回 `{"type":"pong"}` |

### `/device_pipeline`

流水线事件通道，支持生产者与订阅者两种角色。

生产者 URL：

```text
ws://<host>:9000/device_pipeline?device_id=<id>
```

订阅者 URL：

```text
ws://<host>:9000/device_pipeline?role=subscriber&device_id=<id>&debug_token=<token>
```

订阅者 `role` 支持 `subscriber`、`sub`、`viewer`、`consumer`；`device_id` 可省略，省略时订阅全部设备。

| 角色 | 方向 | 消息 | 用途 |
|---|---|---|---|
| 全部 | 服务端 -> 客户端 | `{"type":"ready","channel":"device_pipeline",...}` | 通道就绪 |
| 订阅者 | 服务端 -> 客户端 | `{"type":"pipeline_snapshot","items":[...],"device_filter":...,"max_events":100}` | 连接时快照 |
| 订阅者 | 服务端 -> 客户端 | `{"type":"pipeline_event","event":{...}}` | 一轮 ASR/LLM/TTS 或自动下发事件 |
| 订阅者 | 服务端 -> 客户端 | `{"type":"pipeline_stage","event":{...}}` | 阶段事件，例如 `pb_ack`、`face_pos` |
| 生产者 | 客户端 -> 服务端 | 任意 JSON 事件，含 `asr_text`、`llm_text`、`tts_text`、耗时、状态等 | 归一化后写入流水线窗口 |
| 生产者 | 服务端 -> 客户端 | `{"type":"pipeline_ack","seq":N}` | 事件已接收 |
| 生产者 | 服务端 -> 客户端 | `{"type":"pipeline_rejected","reason":"invalid_payload"}` | 事件无效 |
| 全部 | 客户端 -> 服务端 | `{"type":"ping"}` | 服务端回 `pong` |

### `/camera`

旧独立相机通道已移除。连接会收到错误消息并以 close code `1008` 关闭，应改用 `/asr_chat` 的 `camera_frame`。

## deskbot HTTP API `:9000`

所有 `/api/*` 均支持 `OPTIONS` CORS 预检。除 `/health` 外，鉴权走 Web 会话或 `debug_token`（无 user_id 时匿名放行）。

| 方法 | 路径 | 用途 | 主要输入 |
|---|---|---|---|
| GET | `/health` | 存活探针 | - |
| GET | `/api/devices` | 当前在线设备列表；登录用户按绑定设备过滤 | - |
| GET | `/api/asr_auto_reply` | 查询/设置 ASR 自动应答开关 | query: `enabled=1|0|true|false` 可选 |
| GET | `/api/camera_servo_auto_mode` | 查询/设置相机舵机自动模式 | query: `mode=follow|follow_frontal|gaze|off` 可选 |
| GET | `/api/debug_prefs` | 查询/批量设置调试偏好 | query: `asr_auto_reply`, `camera_servo_auto_mode` 可选 |
| GET | `/api/pipeline_recent` | 获取流水线事件滚动窗口 | query: `device_id` 可选，`limit` 默认最多 100 |
| GET | `/api/device_servo` | 向设备 `/asr_chat` 下发单片舵机 pb | query: `device_id`, `dyaw`, `dpitch`, `ms`, `xm`, `ym`, `action`, `level`, `with_scene`/`append_scene` |
| GET | `/api/device_pb_scenes` | 列出内置/配置的 pb 场景名 | - |
| GET/POST | `/api/device_tts` | 跳过 LLM，直接 TTS 并下发到设备 | query 或 JSON: `device_id`, `text`, `scene` 可选 |
| GET/POST | `/api/scene_playbook/run` | 执行场景 playbook，并与 TTS/表情/舵机交错下发 | GET: `device_id`, `name`; POST JSON: `device_id`, `playbook` 或 `name` |
| GET | `/api/device_pb_scene` | 按场景名向设备顺序下发 `pb_start -> pb_chunk* -> pb_end` | query: `device_id`, `scene` |
| GET/POST | `/api/servo_config` | 读取/写入舵机配置文件 | query/JSON: `device_id` 可选；POST body 为 servo 文档 |
| GET/POST | `/api/face_mouth_by_phoneme` | 读取/写入音素口型组表 | query/JSON: `device_id` 可选；POST body 为组表 |
| GET/POST | `/api/device_pb_anim` | 下发仅含 `anim` 的单片 `pb_single` | GET: `device_id`, `anim_b64`, `chunk_ms`, `action`, `level`; POST JSON: `device_id`, `anim`, `chunk_ms`, `action`, `level` |
| GET/POST | `/api/face_expr_scenes` | 读取/写入设计表情场景 | query/JSON: `device_id` 可选；POST body 为场景数组 |
| GET | `/api/device_pb_expr_scene` | 按设计表情场景名向设备下发 pb 链 | query: `device_id`, `scene` 或 `name` |

未知 `/api/*` 返回 `404 {"error":"not found","path":"..."}`。不支持的方法返回 `405`。

## 源码索引

| 范围 | 文件 |
|---|---|
| FastAPI 主服务与路由组装 | `service/src/deskbot_server/controller/app.py` |
| Web 控制台账号路由 | `service/src/deskbot_server/web/blueprints/auth_bp.py` |
| Web 管理后台路由 | `service/src/deskbot_server/web/blueprints/app_bp.py` |
| 2C 页面/API 路由 | `service/src/deskbot_server/web/blueprints/app2c_bp.py` |
| Web 调试路由 | `service/src/deskbot_server/web/blueprints/debug_bp.py` |
| Web 到 deskbot 代理 | `service/src/deskbot_server/web/blueprints/proxy_bp.py` |
| `/asr_chat` 会话处理 | `service/src/deskbot_server/service/device_ws_service.py` |
| `/device_pipeline` 协议 | `service/src/deskbot_server/ws/device_pipeline.py` |
| `/camera_view` 预览 | `service/src/deskbot_server/controller/web_controller.py` |
| TTS 适配（豆包 doubao） | `service/src/deskbot_server/infrastructure/tts/` |
| 人脸检测 / 跟随 | `service/src/deskbot_server/vision/`、`service/src/deskbot_server/service/camera_face_service.py` |

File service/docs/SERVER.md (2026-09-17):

# deskbot-server

主服务：VAD → 外部 funasr 服务（独立进程，9102）→ LLM（多轮 tools）→ TTS → pb 下行。环境搭建见 [../README.md](../README.md)。

## 启动

```bash
# 一键启动（含 Web 控制台）
./start.sh
SKIP_SETUP=1 ./start.sh
```

```bash
cp .env.example .env   # 填 SILICONFLOW_API_KEY（系统默认大脑，硅基流动）
```

| 端口 | 服务 |
|---|---|
| **9000** | WebSocket + HTTP API + FastAPI Web 控制台（同一主服务进程，随 start.sh 一并启动） |

---

## Web 控制台（`:9000`）

邮箱注册 / 登录后可用：

| 路径 | 说明 |
|---|---|
| `/app` | 工作台：用量概览 |
| `/app/devices` | 我的设备：绑定、切换 `device_id` |
| `/app/scheduled-tasks` | 定时任务：cron 任务列表（东八区），可删除 |
| `/app/memories` | 记忆：按设备增删改查长期记忆 |
| `/app/face-profiles` | 人脸识别：按设备查看档案 |
| `/app/usage` | 用量看板：按设备统计 |
| `/app/settings` | 账号设置：资料、密码、LLM 模型配置 |
| `/debug/devices` | 调试：在线设备、流水线 |
| `/debug/llm` | 调试：LLM 试聊 |
| `/debug/tts` | 调试：豆包 TTS |
| `/debug/simulation` | 调试：pb 仿真 |

本地联调脚本可读取 `data/.free_api_key`（若存在）；设备链路不涉及任何 Key。

---

## WebSocket（`:9000`）

| 路径 | 说明 |
|---|---|
| `/asr_chat?device_id=` | **生产设备**：语音 + 可选 `camera_frame`；pb 下行（仅 `device_id` 鉴权） |
| `/camera_view?device_id=&debug_token=` | 调试：JPEG 预览（控制台签发 debug_token + 设备归属） |
| `/device_pipeline?role=subscriber&device_id=&debug_token=` | 调试：流水线事件（订阅侧 debug_token；生产者仅 `device_id`） |

`device_id` 别名：`device` / `deviceid` / `id`。协议：[../docs/esp32_pb_protocol.md](../docs/esp32_pb_protocol.md)。

默认 **`asr_chat_device_pb_only: true`**：设备只收 `pb_*` + PCM。

---

## HTTP API（`:9000`）

| 路径 | 说明 |
|---|---|
| `/health` | 健康检查（免 Key） |
| `/api/devices` | 在线设备列表 |

**ESP32 设备 WS 仅需 `device_id`**；HTTP `/api/*` 走 Web 会话（无 user_id 时匿名放行）。

---

## LLM 与工具

对话采用 **JSON 回复 + `tools` 数组**；有 tools 时服务端执行后再次调用 LLM（最多 8 轮），无 tools 时走 TTS / pb。

| 工具 | 说明 |
|---|---|
| `schedule_task` | cron 定时任务增删改查（北京时间）；用户说「N 分钟后提醒我…」时**必须**调用，禁止口头答应 |
| `set_camera_follow` | 人脸舵机跟随 |
| `capture_camera` | 获取最近相机帧 |
| `register_face` | 注册 / 更新人脸档案 |
| `memory_add` / `memory_delete` | 长期记忆 |
| `session` | 查询对话 session |
| `webfetch` / `websearch` | 联网抓取 / 搜索 |
| `read` / `write` | 读写 `data/{device_id}/tmp/` |

定时任务由后台调度器每分钟轮询，到期后复用创建时的 `session_id` 作为 LLM 上下文并播报提醒。

人设与工具说明：`data/global/llm_system.txt`（全局模板，所有设备共用，不再复制到设备目录）。

---

## 设备数据（按 `device_id` 隔离）

运行时数据在 `data/{device_id}/`（**不入 Git**），共享配置在 `data/global/`：

| 文件 / 目录 | 说明 |
|---|---|
| `data/global/llm_system.txt` | 全局 LLM 人设模板 |
| `user_memory.json` | 长期记忆 |
| `face_profiles.json` | 人脸档案 |
| `session/` | 对话 session（10 分钟无对话开新 session） |
| `tmp/` | LLM `read` / `write` 沙箱目录 |

全局 SQLite：`data/opendesk.db`（用户、设备绑定、`scheduled_tasks`、用量等表）。

---

## 配置

- **`.env`**：`SILICONFLOW_API_KEY`（硅基流动，**系统默认大脑的密钥**；`config.yaml` 的 `llm.api_key_env` 指名此变量，`llm_provider` 为空的设备共用它——见下方「LLM 密钥分层」）、`ARK_API_KEY` / `ARK_MODEL`（火山方舟，仅设备选用 ark 时需要；密钥实际存 `devices.llm_param["ark"]`）、`DOUBAO_TTS_*`（豆包 TTS）、`DOUBAO_ASR_API_KEY` / `DOUBAO_ASR_RESOURCE_ID` / `DOUBAO_ASR_UID`（豆包 ASR 2.0 全局兜底凭证；设备级配置优先存 `devices.asr_param`）、`ASR_MODEL_DIR`、`DESKBOT_WEB_PUBLIC_HOST`（多网卡时填局域网 IP）、`DESKBOT_WEB_SECRET_KEY`（生产必设）
- **LLM 密钥分层**：系统默认（`config.yaml` llm 段，当前 = 硅基流动）的密钥是**服务端公共凭证**，从 `llm.api_key_env` 指名的环境变量读取，所有未单独配置的设备共用；设备级 `ark` 的密钥存在设备表 `llm_param["ark"]`，互不影响。**改 `.env` 后必须重启服务**才生效（`load_dotenv` 只在启动时读一次）。
- **`config.yaml`**：`audio.input_codec`、`llm.*`（系统默认大脑：protocol / base_url / model_name / api_key_env / context_window）、`tts.provider`（`moss-tts-nano` 默认 / `doubao`）、`server.asr_chat_device_pb_only`、`debug.asr_auto_reply`

架构概要：[docs/ARCHITECTURE.md](docs/ARCHITECTURE.md)。

---

## 联调

```bash
source .venv/bin/activate
python tools/test_client.py \
  --ws-url "ws://127.0.0.1:9000/asr_chat?device_id=deskbot_dev" \
  --input-wav demo_16k_mono.wav
```

更多脚本见 [tools/README.md](tools/README.md)。

```bash
source .venv/bin/activate
pytest tests/ -q
```

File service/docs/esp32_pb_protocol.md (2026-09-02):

# ESP32 与 BotServer 通信协议（pb v2.1）

单条 WebSocket：`ws://<host>:9000/asr_chat?device_id=<id>`。文本 JSON 与 binary 交替，**不用 base64**。长度由 **`next_bin_len`** 声明（上行在 JSON 根；下行在 `audio.next_bin_len`）。旧版 `audio.next_bin: 1` 已废弃。

> **相关文档：** 部署与快速使用见 [README.md](../README.md)；主服务配置见 [SERVER.md](./SERVER.md)。定时任务、长期记忆、控制台管理等为**服务端能力**，不扩展本设备协议字段。

默认 **`asr_chat_device_pb_only: true`**：设备下行只处理 **`pb_*` + PCM**。服务端不再下发 `face_info`、`asr_*`、`llm_text`、TTS/错误类 JSON（如 `playback_done`、`tts_error`、`error`、`asr_rejected` 等）；轮次结果与耗时见 `/device_pipeline` 的 `pipeline_event` 或 Web 调试台。

---

## 0. 鉴权（设备端必读）

### 0.1 适用范围

| 通道 | 路径 | 鉴权 |
|---|---|---|
| 生产主链路 | `/asr_chat` | **`device_id` 必须**（仅此一项）；含语音与 `camera_frame` |
| 摄像头预览 | `/camera_view` | 控制台签发的 **`debug_token`** + 设备归属 |
| 流水线订阅 | `/device_pipeline` 订阅侧 | 控制台签发的 **`debug_token`** + 设备归属 |
| 流水线生产者 | `/device_pipeline` | **`device_id` 必须**（仅此一项） |
| HTTP API | `/api/*` | Web 会话或 debug token；无 user_id 时匿名放行 |
| 健康检查 | `/health` | 否 |

**设备链路无 API Key、无 PIN**；`debug_token` 由 Web 控制台「调试台」为已登录用户签发（`GET /api/debug/ws_token`）。

### 0.2 设备连接 URL

```
ws://<host>:9000/asr_chat?device_id=deskbot_abc123
```

### 0.3 失败行为（设备 WS）

| 情况 | WebSocket |
|---|---|
| 缺少 `device_id` | 关闭码 **1008**，reason `device_id_required` |
| 重复连接 | 同一 `device_id` 只保留最新一条（`keep_only_one_link`） |

### 0.4 Web / 调试鉴权（仅控制台与调试）

Web 控制台（`:9000`）注册登录后，会话 cookie 即 Web / HTTP 鉴权；`/camera_view` 与 `/device_pipeline` 订阅侧使用 `debug_token`（`GET /api/debug/ws_token` 签发，URL 参数名 `debug_token` / `debugtoken` / `ws_token`）。设备主链路不涉及任何 Key。

### 0.5 固件最小接入示例

```c
// 伪代码
const char *url =
  "ws://192.168.1.10:9000/asr_chat"
  "?device_id=deskbot_1cdbd476ab5c";
websocket_connect(url);
```

---

## 1. 传输规则

| 规则 | 说明 |
|---|---|
| 成对顺序 | 若 JSON 声明 `next_bin_len > 0`，下一条 WS **必须**为等长 binary，再收下一条 JSON |
| 错位 | 预期 binary 却收到 JSON，或长度不符 → 丢弃该帧/序列，勿把 JPEG 送进 ASR |
| 独立 `/camera` | 已移除（连接返回 1008） |
| 兼容 | 裸 binary 无 JSON 仍当旧版音频（新固件勿用） |

**上下行对照**

| 方向 | 声明 | binary 内容 |
|---|---|---|
| 上行 | 根级 `"next_bin_len": N` | Opus / PCM16 / JPEG |
| 下行 pb | `"audio": {"next_bin_len": N, "frames": F?}` | **opus** batch 或 s16le PCM |

---

## 2. 上行（设备 → 服务端）

### 2.1 音频 `audio`

`codec` 与 `config.yaml` → `audio.input_codec` 一致（常见 **opus** @ 16 kHz）。

```json
{ "type": "audio", "codec": "opus", "next_bin_len": 80 }
```

下一条 80 字节 Opus。PCM 示例：`codec":"pcm16"`, `sr`:16000, `ch`:1。

**段结束**（无 binary）：

```json
{ "type": "flush" }
```

触发 ASR → LLM → TTS → pb 下行。

### 2.2 画面 `camera_frame`

```json
{ "type": "camera_frame", "codec": "jpeg", "next_bin_len": 12345, "seq": 42 }
```

下一条为 JPEG。下行 pb 可用 **`cam_fps`**（如 `3` = 每秒 3 帧）调节上行帧率；发送侧建议丢旧保新。

### 2.3 其它

| `type` | 说明 |
|---|---|
| `ping` | 服务端回 `pong` |
| `pb_ack` | 播放回压，见 §8 |
| `user_text` | 调试：跳过 ASR |

**示例顺序**

```
JSON audio + next_bin_len → BIN opus
JSON camera_frame → BIN jpeg
JSON flush
```

---

## 3. 下行 pb 概述

| 项目 | 约定 |
|---|---|
| 版本 | `pb_ver: 2`（wire v2.1） |
| 音频 | mono **opus**（默认，`config.yaml` → `audio.output_codec`）或 **s16le**，**sr = 16000**（首包声明，统一下发采样率） |
| 画布 | **284 × 240**，原点左上 |
| 单包 | 硬件上限 `chunk_ms ≤ 10000`；服务端合并默认 ≤ **500**（`PB_CHUNK_MS_MAX`） |
| 口播默认 | `level = 1`，`action = "replace"` |

一条 pb JSON 可含 **`anim[]`**（表情）、**`servo[]`**（舵机）、**`audio`**（PCM 长度）。口播由服务端按音素组帧后合并为多片 `pb_start` → `pb_chunk*` → `pb_end`，或单片 **`pb_single`**。

**全局规则（固件必实现）**

| 编号 | 规则 |
|---|---|
| R0 | `pb_start`/`pb_chunk`/`pb_end`/`pb_single` 中 `audio`/`servo`/`anim` 至少一项 |
| R1 | 队列决策仅 **`pb_start`**、**`pb_single`**；同 `req` 的 `pb_chunk`/`pb_end` 只续传 |
| R2 | `audio.next_bin_len > 0` → 下一条为等长 audio binary（opus batch 或 s16le PCM） |
| R3 | 协议错位 → 丢弃该 `req` 剩余片，清队列 |
| R4 | 同 `req` 内 `idx` 从 0 严格递增 |
| R5 | 有 `anim[]` 时 `sum(anim[i].ms) == chunk_ms` |
| R6 | PCM 字节数 `== (chunk_ms * sr // 1000) * 2` |

24 kHz：`chunk_ms=113` → 5424 字节；`chunk_ms=1921` → 92112 字节。固件 WS RX 缓冲须能容纳单帧 binary（默认可至约 480000 字节 / 10s）。

---

## 4. 下行消息类型

| `type` | 用途 |
|---|---|
| `pb_start` | 链首包（`idx=0`），触发队列；含音频时带 `sr`/`fmt`/`ch` |
| `pb_chunk` | 链中间包 |
| `pb_end` | 链末包 |
| `pb_single` | 整轮仅一条（idle、单段舵机、或口播仅一包） |
| `pb_cancel` | 中止 `req` |

多片：`pb_start`(0) → `pb_chunk`(1…N-2) → `pb_end`(N-1)。单片只发 **`pb_single`**，禁止无 `pb_start` 单发 `pb_end`。

### 4.1 公共字段

| 字段 | 说明 |
|---|---|
| `req` | 序列 ID（16 位 hex 常见） |
| `idx` | 分片序号，从 0 递增 |
| `chunk_ms` | 本片时长（ms） |
| `level` | 优先级 0–3：0 idle，1 口播，2 紧急，3 调试 |
| `action` | `replace`（默认）\| `append` \| `default` |
| `volume` | 0–100，可选；同 `req` 后续 PCM 按此音量 |
| `cam_fps` | >0 时设置 JPEG 上行目标帧率 |

忽略以 `_` 开头的键。

### 4.2 时序示例

```
→ JSON pb_start  audio.next_bin_len=N  chunk_ms=T  anim[…]
→ BINARY N 字节 PCM
→ JSON pb_chunk …
→ BINARY …
→ JSON pb_end …
→ BINARY …
```

---

## 5. 动画 `anim[]`

`anim` **必须是数组**。每项：

| 字段 | 说明 |
|---|---|
| `elements` | 图层容器（见下表） |
| `ms` | 该段子动画时长（≥1） |
| `phoneme` | 可选，音素符号（调试） |

### 5.1 `elements` 图层

| 键 | 说明 |
|----|---|
| `bg` | 背景（最先绘制） |
| `nose` | 鼻 |
| `mouth` | 口型 |
| `eye_l` / `eye_r` | 左/右眼 |
| `extra` | 装饰（腮红、文字等） |

### 5.2 片内时间轴

```
t = 0
for k in 0 .. anim.length-1:
  在 [t, t + anim[k].ms) 绘制 anim[k].elements
  t += anim[k].ms
```

有 PCM 时子动画切换与采样边界对齐。

### 5.3 绘制顺序

**`bg` → `nose` → `mouth` → `eye_l` → `eye_r` → `extra`**

### 5.4 图元与颜色

每个图元须有 **`shape`**（比较前转小写、做别名归一化）。wire 上颜色为 **`c`（RGB565 整数）**；配置 JSON 可写 `#RGB` / 命名色，服务端转换；缺省 **65535（白）**。

```
R5 = (R8 >> 3) & 0x1F;  G6 = (G8 >> 2) & 0x3F;  B5 = (B8 >> 3) & 0x1F
c  = (R5 << 11) | (G6 << 5) | B5
```

未知 `shape`：**跳过**该图元，不判整包失败。
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

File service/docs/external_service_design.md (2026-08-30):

# 外部服务设计模式与后台交互规范（以 insightface-engine 为例）

> 面向后续「新增/改造外部独立进程服务」任务的实践指南：设计原理、配置自治、
> 后台界面交互要点、落地清单与踩坑记录。
> 框架层面的 manifest 契约/状态机/API 见 [external_services.md](./external_services.md)。

## 一、架构设计原理

**独立进程 + HTTP 契约，生命周期交管理器，业务零耦合。**

```
┌──────────────────────┐  service.yaml（name/type/port/start/healthcheck/auto_start）
│  主服务 deskbot-server │ ── ExternalServiceManager：discover → start/stop/watchdog/自动重启
│ （独立服务管理页）      │
└──────────┬───────────┘
           │ HTTP 127.0.0.1:<port>（确定性契约，见 contract.py CONTRACTS）
┌──────────▼───────────┐
│ insightface-engine    │  server.py + config.yaml（完全自治）
└──────────────────────┘
```
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

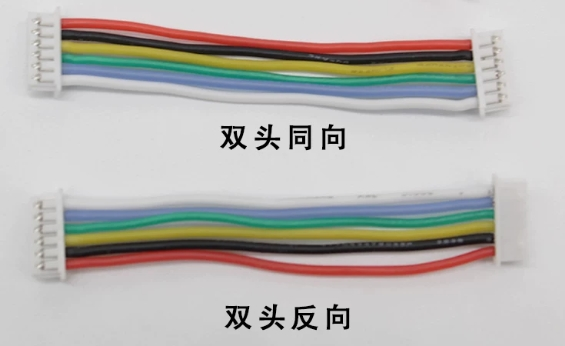
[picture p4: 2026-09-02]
hardware/mechanical/连接线_双向同头示意图.png

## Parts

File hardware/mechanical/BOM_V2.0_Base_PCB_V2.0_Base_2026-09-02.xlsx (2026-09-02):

No. | Quantity | Comment | Designator | Footprint | Value | Manufacturer Part | Manufacturer | Supplier Part | Supplier
1 | 2 | TS-1088R-02026 | BOOT1,RST1 | SW-SMD_L3.9-W3.0-P4.45 |  | TS-1088R-02026 | XUNPU(讯普) | C455280 | LCSC
2 | 3 | 10uF | C1,C10,C11 | C0402 | 10uF | HGC0402R5106M100NTEJ | Chinocera(华瓷) | C7472949 | LCSC
3 | 6 | 100nF | C2,C7,C8,C12,C14,C23 | C0402 | 100nF | CL05B104KO5NNNC | SAMSUNG(三星) | C1525 | LCSC
4 | 1 | 100uF | C3 | CASE-A_3216 | 100uF | TLJA107M006R0800 | Kyocera AVX | C27279 | LCSC
5 | 6 | 1uF | C4,C9,C19,C20,C21,C22 | C0402 | 1uF | CL05A105KO5NNNC | SAMSUNG(三星) | C29266 | LCSC
6 | 2 | 1nF | C5,C6 | C0402 | 1nF | GCM155R71H102KA37D | muRata(村田) | C126532 | LCSC
7 | 1 | 4.7uF | C13 | C0402 | 4.7uF | CL05A475KP5NRNC | SAMSUNG(三星) | C368809 | LCSC
8 | 2 | 22uF | C15,C16 | C0402 | 22uF | HGC0402R5226M100NTEJ | Chinocera(华瓷) | C22367823 | LCSC
9 | 1 | 6.8pF | C17 | C0402 | 6.8pF | CC0402CRNPO9BN6R8 | YAGEO(国巨) | C189470 | LCSC
10 | 1 | 2.2uF | C18 | C0402 | 2.2uF | CL05A225KP5NSNC | SAMSUNG(三星) | C107369 | LCSC
11 | 1 | AFC01-S24FCA-00 | FPC1 | FPC-SMD_24P-P0.50_AFC01-S24FCA-00 |  | AFC01-S24FCA-00 | JS(钜硕电子) | C262669 | LCSC
12 | 2 | PZ254V-11-03P | H1,H2 | HDR-TH_3P-P2.54-V-M_PZ254V-11-03P |  | PZ254V-11-03P | XFCN(兴飞) | C2937625 | LCSC
13 | 1 | PZ254V-11-02P | H3 | HDR-TH_2P-P2.54-V-M |  | PZ254V-11-02P | XFCN(兴飞) | C492401 | LCSC
14 | 2 | CBG100505U000T | L1,L2 | L0402 |  | CBG100505U000T | FH(风华) | C139137 | LCSC
15 | 1 | 2.2uH | L3 | L0402 | 2.2uH | MLZ1005M2R2WT000 | TDK | C383389 | LCSC
16 | 1 | 1.25-6P LT | LCD1 | CONN-SMD_1.25-6PLT |  | 1.25-6P LT | SHOU HAN(首韩) | C668613 | LCSC
17 | 1 | GL0603UG01 | LED1 | LED0603-RD |  | GL0603UG01 | Guiguang light(桂光光电) | C51933293 | LCSC
18 | 1 | 1kΩ | R1 | R0402 | 1kΩ | FRC0402J102 TS | FOJAN(富捷) | C2906899 | LCSC
19 | 2 | 5.1kΩ | R2,R5 | R0402 | 5.1kΩ | FRC0402F5101TS | FOJAN(富捷) | C2906874 | LCSC
20 | 5 | 10kΩ | R3,R4,R6,R8,R16 | R0402 | 10kΩ | FRC0402F1002TS | FOJAN(富捷) | C2906861 | LCSC
21 | 1 | 2.7kΩ | R7 | R0402 | 2.7kΩ | FRC0402F2701TS | FOJAN(富捷) | C2909332 | LCSC
22 | 1 | 450kΩ | R9 | R0402 | 450kΩ | FRC0402F4503TS | FOJAN(富捷) | C5159688 | LCSC
23 | 2 | 100kΩ | R10,R14 | R0402 | 100kΩ | FRC0402F1003TS | FOJAN(富捷) | C2906859 | LCSC
24 | 1 | 680kΩ | R11 | R0402 | 680kΩ | FRC0402F6803TS | FOJAN(富捷) | C2909377 | LCSC
25 | 1 | 150kΩ | R12 | R0402 | 150kΩ | FRC0402F1503TS | FOJAN(富捷) | C2909320 | LCSC
26 | 2 | 1Ω | R13,R15 | R0805 | 1Ω | CRCW08051R00FKEAHP | VISHAY(威世) | C313850 | LCSC
27 | 1 | 1.25-2P | SPK_CN1 | CONN-SMD_1.25-2P |  | 1.25-2P | SHOU HAN(首韩) | C393945 | LCSC
28 | 1 | LMV358ARZ | U1 | SOP-8_L4.9-W3.9-P1.27-LS6.0-BL |  | LMV358ARZ | HTCSEMI(海天芯) | C2928823 | LCSC
29 | 1 | NS4168 | U2 | ESOP-8_L4.9-W3.9-P1.27-LS6.0-BL-EP |  | NS4168 | Nsiway(纳芯威) | C910588 | LCSC
30 | 1 | DIO7002AST5 | U3 | SOT-23-5_L3.0-W1.7-P0.95-LS2.8-BR |  | DIO7002AST5 | DIOO(帝奥微) | C403840 | LCSC
31 | 1 | 2.4GHz | U4 | WIRELM-SMD_ESP32-S3-WROOM-1U | 2.4GHz | ESP32-S3-WROOM-1U-N16R8 | ESPRESSIF(乐鑫) | C3013946 | LCSC
32 | 1 | HM8089 | U5 | TSOT-23-5_L2.9-W1.6-P0.95-LS2.8-BR |  | HM8089 | GATEMODE(捷茂微) | C2693745 | LCSC
33 | 1 | XC6206P282MR | U6 | SOT-23-3_L2.9-W1.3-P0.95-LS2.4-BR |  | XC6206P282MR | HXY MOSFET(华轩阳电子) | C5148690 | LCSC
34 | 1 | XC6206P122MR-G-HXY | U7 | SOT-23-3_L2.9-W1.6-P1.90-LS2.8-BR |  | XC6206P122MR-G-HXY | HXY MOSFET(华轩阳电子) | C42411833 | LCSC
35 | 1 | LMD2718T271-OA5 | U8 | MIC-SMD_6P-L2.8-W1.9_LMD2718T271-OA5 |  | LMD2718T271-OA5 | LinkMems(聆麦声学) | C22379480 | LCSC
36 | 1 | TYPE-C 16PIN 2MD(073) | USB1 | USB-C-SMD_TYPE-C-16PIN-2MD-073 |  | TYPE-C 16PIN 2MD(073) | SHOU HAN(首韩) | C2765186 | LCSC

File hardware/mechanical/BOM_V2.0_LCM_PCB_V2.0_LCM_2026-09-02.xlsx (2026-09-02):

No. | Quantity | Comment | Designator | Footprint | Value | Manufacturer Part | Manufacturer | Supplier Part | Supplier
1 | 1 | 100nF | C12 | C0402 | 100nF
2 | 1 | FPC-05F-12PH20 | FPC1 | FPC-SMD_12P-P0.50_FPC-05F-12PH20 |  | FPC-05F-12PH20 | XUNPU(讯普) | C2856799 | LCSC
3 | 1 | 1.25-6P WT | LCD | CONN-SMD_1.25-6PWT |  | 1.25-6P WT | SHOU HAN(首韩) | C668617 | LCSC
4 | 1 | 10K | R1 | R0402 | 10K
5 | 1 | 100Ω | R32 | R0402 | 100Ω

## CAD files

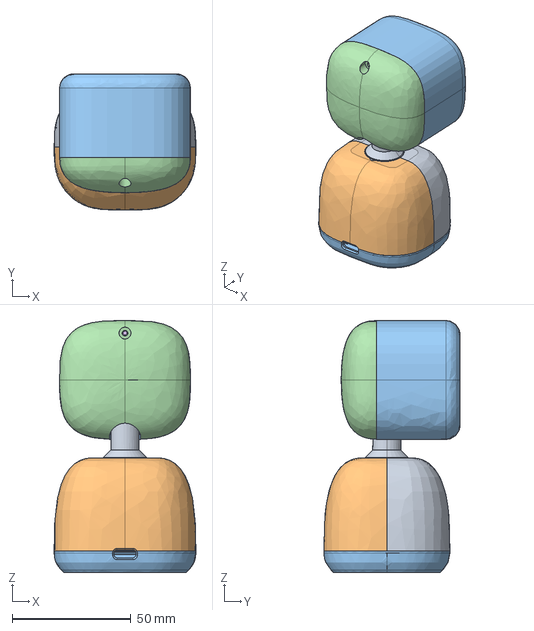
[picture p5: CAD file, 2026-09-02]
hardware/mechanical/小歪机器人v2.0打印件stp.stp
59.7 x 57.4 x 106.2 mm

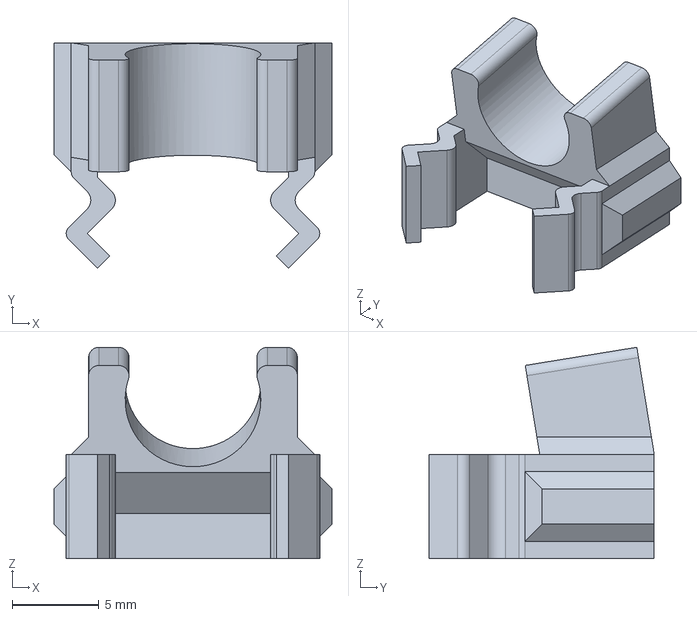
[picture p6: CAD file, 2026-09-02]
hardware/mechanical/小歪机器人v2.0 ov3660摄像头卡子.stp
16.0 x 13.0 x 12.2 mm

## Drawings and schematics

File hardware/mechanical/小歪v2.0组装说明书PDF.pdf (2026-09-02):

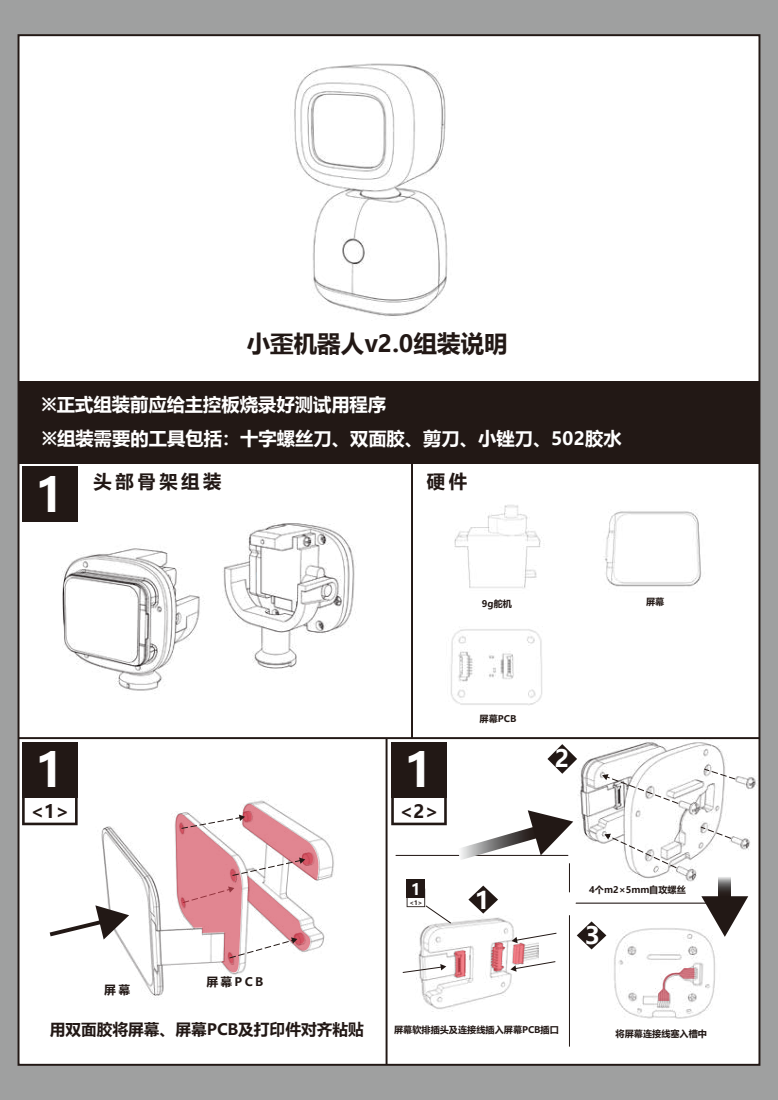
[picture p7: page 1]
小歪机器人v2.0组装说明; 头部骨架组装; 用双面胶将屏幕、屏幕PCB及打印件对齐粘贴; 屏幕软排插头及连接线插入屏幕PCB插口; 将屏幕连接线塞入槽中; 4个m2×5mm自攻螺丝; 9g舵机; 屏幕PCB

※正式组装前应给主控板烧录好测试用程序
※组装需要的工具包括：十字螺丝刀、双面胶、剪刀、小锉刀、502胶水

# ※注意将连接线如图引出

1

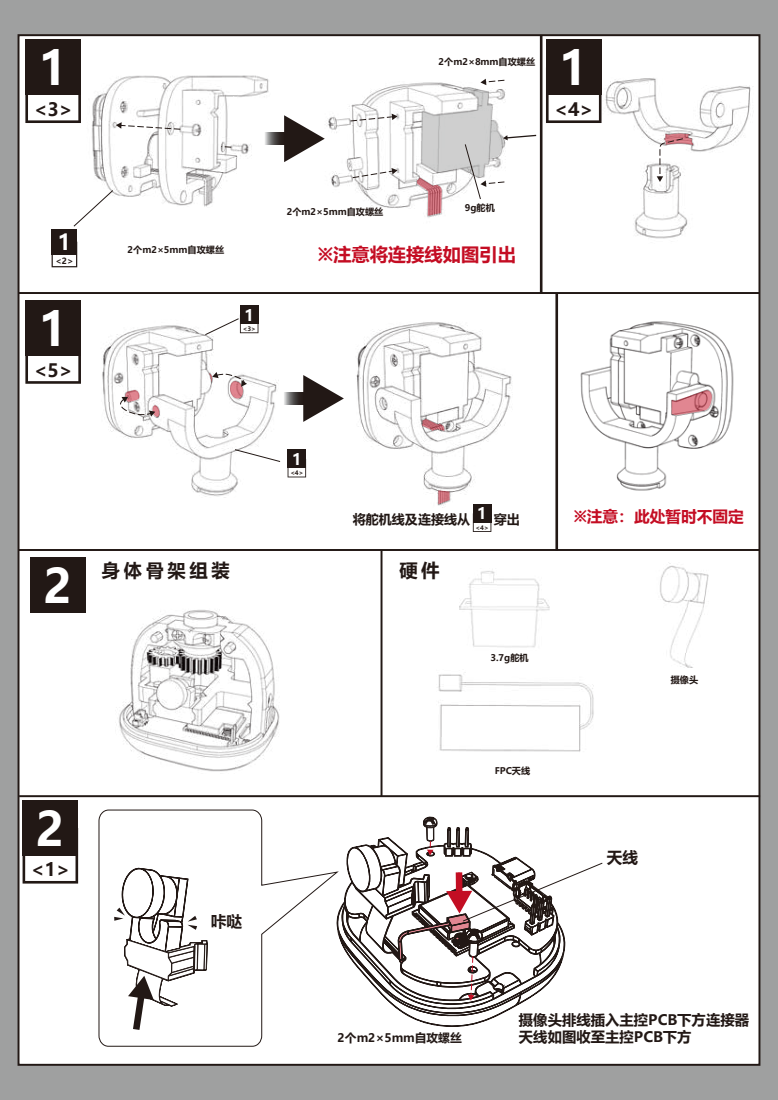
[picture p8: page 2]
2个m2×5mm自攻螺丝; 摄像头排线插入主控PCB下方连接器 天线如图收至主控PCB下方; 将舵机线及连接线从; ※注意：此处暂时不固定; 2个m2×8mm自攻螺丝; 9g舵机; 3.7g舵机; FPC天线; 摄像头; 身体骨架组装 2

2

<2>

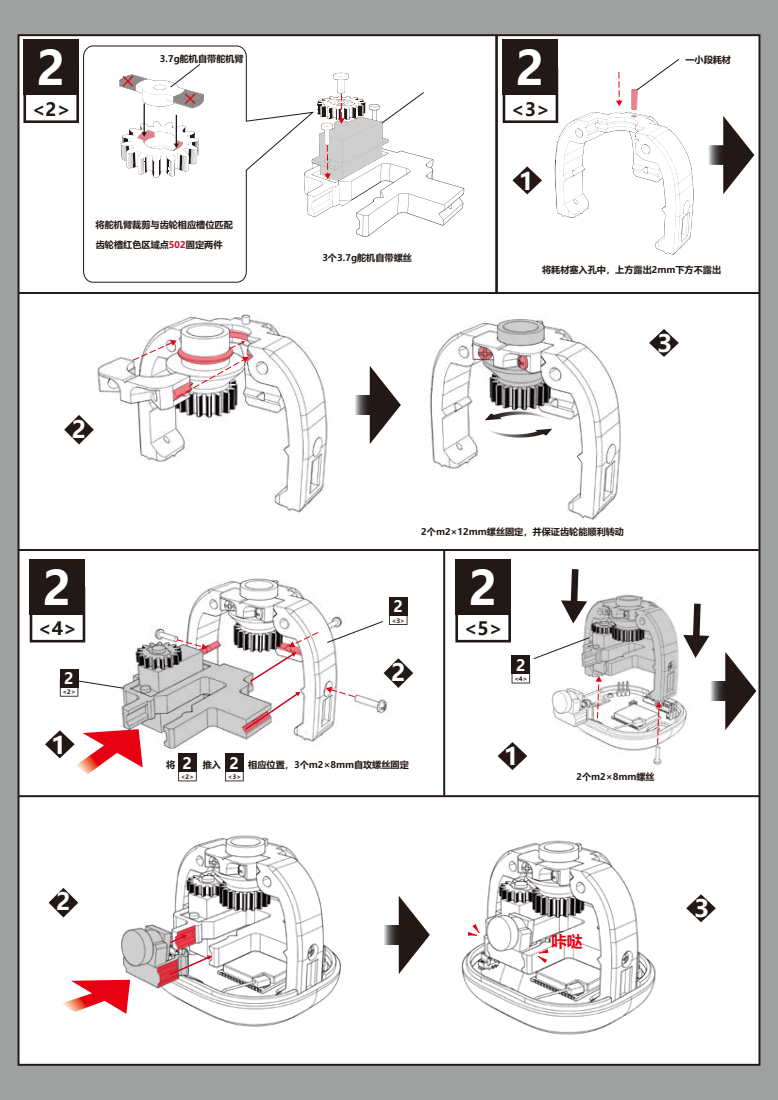
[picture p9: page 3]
3个3.7g舵机自带螺丝; 将舵机臂裁剪与齿轮相应槽位匹配; 3.7g舵机自带舵机臂; 一小段耗材; 将耗材塞入孔中，上方露出2mm下方不露出; 2个m2×12mm螺丝固定，并保证齿轮能顺利转动; 2个m2×8mm螺丝; 齿轮槽红色区域点502固定两件; 相应位置，3个m2×8mm自攻螺丝固定 2

# 将屏幕排线及9g舵机线 穿过身体到底部主控PCB

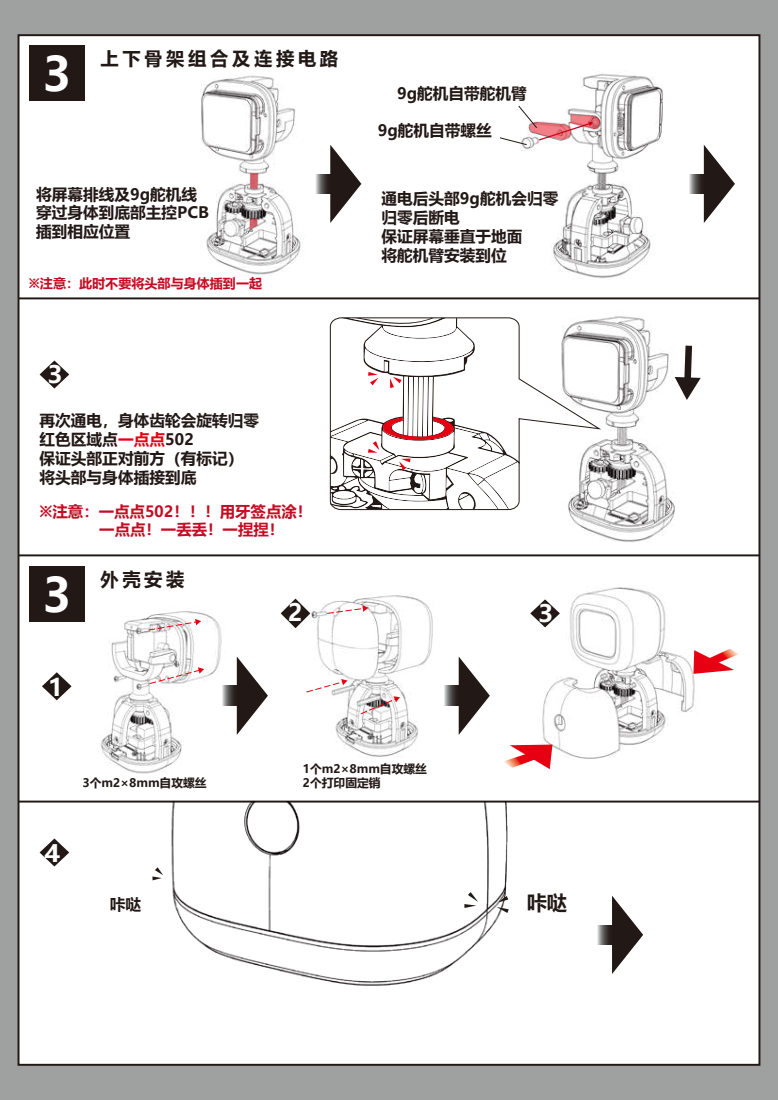
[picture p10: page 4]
插到相应位置; 通电后头部9g舵机会归零 归零后断电 保证屏幕垂直于地面 将舵机臂安装到位; 3个m2×8mm自攻螺丝; 1个m2×8mm自攻螺丝 2个打印固定销; ※注意：此时不要将头部与身体插到一起; 上下骨架组合及连接电路 3; 9g舵机自带舵机臂; 9g舵机自带螺丝

再次通电，身体齿轮会旋转归零
红色区域点一点点502
保证头部正对前方（有标记）
将头部与身体插接到底
※注意：一点点502！！！用牙签点涂！
一点点！一丢丢！一捏捏！
外壳安装 3

5

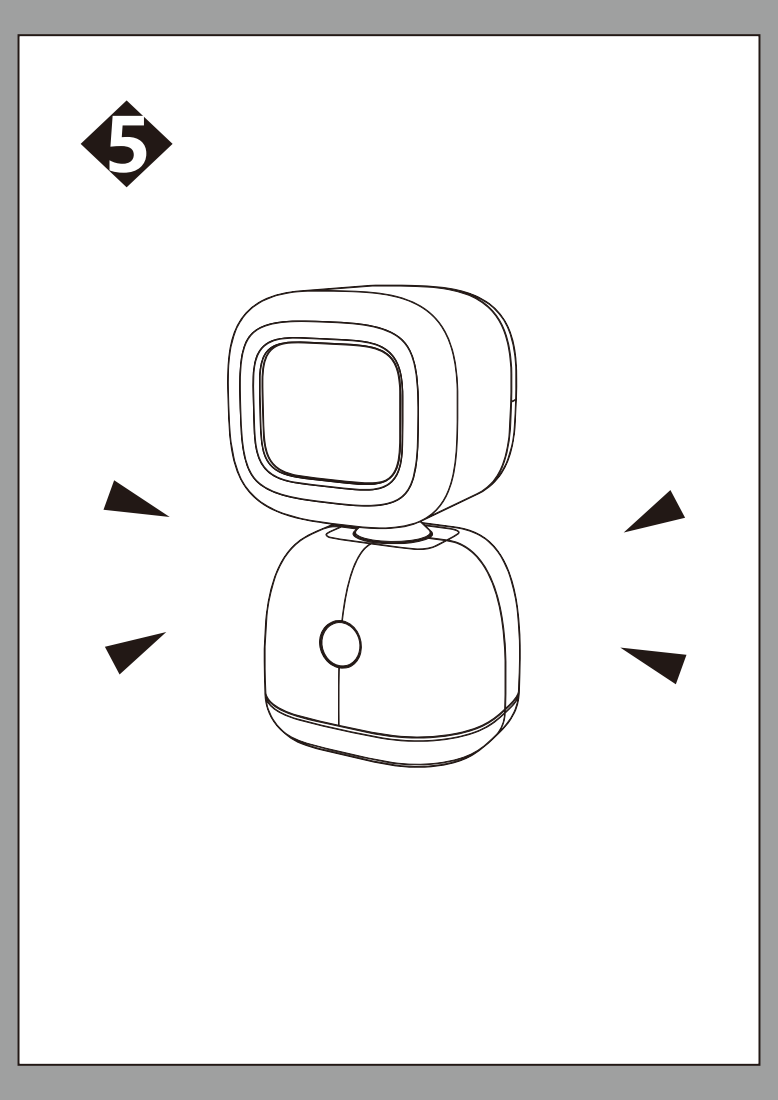
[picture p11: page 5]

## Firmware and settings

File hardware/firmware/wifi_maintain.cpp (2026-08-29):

#include "wifi_provision_internal.h"

#include "boot_guide.h"

void wifi_notify_link_down(void) {
  g_wifi_was_up = false;
  g_wifi_reconnect_pending = true;
  g_wifi_last_reconnect_ms = 0;
  if (g_wifi_link_down_handler) {
    g_wifi_link_down_handler();
  }
}

void wifi_notify_link_up(void) {
  g_wifi_reconnect_pending = false;
  g_wifi_quick_reconnect_active = false;
  g_wifi_reconnect_backoff_ms = 3000;
  wifi_apply_runtime_keepalive();
  boot_guide_wifi_on_connected(WiFi.SSID().c_str(), WiFi.localIP().toString().c_str());
  if (!g_wifi_was_up && g_wifi_link_up_handler) {
    g_wifi_link_up_handler();
  }
  g_wifi_was_up = true;
}

void wifi_register_event_handlers_once(void) {
  if (g_wifi_handlers_registered) {
    return;
  }
  g_wifi_handlers_registered = true;
  WiFi.onEvent([](WiFiEvent_t event, WiFiEventInfo_t info) {
#if defined(ARDUINO_EVENT_WIFI_STA_DISCONNECTED)
    if (event == ARDUINO_EVENT_WIFI_STA_DISCONNECTED) {
      g_wifi_event_disconnected = true;
      g_wifi_last_disconnect_reason = info.wifi_sta_disconnected.reason;
    } else if (event == ARDUINO_EVENT_WIFI_STA_GOT_IP) {
      g_wifi_event_got_ip = true;
    }
#elif defined(SYSTEM_EVENT_STA_DISCONNECTED)
    if (event == SYSTEM_EVENT_STA_DISCONNECTED) {
      g_wifi_event_disconnected = true;
      g_wifi_last_disconnect_reason = info.disconnected.reason;
    } else if (event == SYSTEM_EVENT_STA_GOT_IP) {
      g_wifi_event_got_ip = true;
    }
#endif
  });
}

void wifi_handle_events_in_main_context(void) {
  if (g_wifi_event_disconnected) {
    g_wifi_event_disconnected = false;
    Serial.printf("[wifi] event: disconnected reason=%u\r\n", (unsigned)g_wifi_last_disconnect_reason);
    wifi_notify_link_down();
  }
  if (g_wifi_event_got_ip) {
    g_wifi_event_got_ip = false;
    if (wifi_link_up()) {
      Serial.printf("[wifi] event: got IP=%s RSSI=%d dBm\r\n", WiFi.localIP().toString().c_str(),
                    WiFi.RSSI());
      wifi_notify_link_up();
    }
  }
}

namespace {

void wifi_try_reconnect_now() {
  if (g_wifi_ssid.length() == 0) {
    g_wifi_ssid = WiFi.SSID();
  }
  // reconnect() only works when the driver still holds a STA config (prior link).
  // After boot/portal failure, disconnect(true) cleared it — use full begin() path.
  if (g_wifi_ssid.length() > 0 && WiFi.SSID().length() > 0) {
    Serial.printf("[wifi] maintain quick reconnect ssid=%s\r\n", g_wifi_ssid.c_str());
    WiFi.reconnect();
    g_wifi_quick_reconnect_active = true;
    g_wifi_quick_reconnect_start_ms = millis();
    return;
  }

  Serial.println("[wifi] maintain full reconnect");
  if (wifi_connect_saved_then_default("maintain", kWifiMaintainConnectAttempts)) {
    wifi_notify_link_up();
    return;
  }
  if (g_wifi_reconnect_backoff_ms < 60000UL) {
    g_wifi_reconnect_backoff_ms *= 2;
    if (g_wifi_reconnect_backoff_ms > 60000UL) {
      g_wifi_reconnect_backoff_ms = 60000UL;
    }
  }
  Serial.printf("[wifi] maintain reconnect failed, next in %lu ms\r\n",
                (unsigned long)g_wifi_reconnect_backoff_ms);
}

}  // namespace

void wifi_provision_set_link_handlers(WifiLinkHandler on_down, WifiLinkHandler on_up) {
  g_wifi_link_down_handler = on_down;
  g_wifi_link_up_handler = on_up;
}

void wifi_provision_maintain() {
  wifi_register_event_handlers_once();
  wifi_handle_events_in_main_context();

  const unsigned long now = millis();
  if (wifi_link_up()) {
    g_wifi_reconnect_pending = false;
    g_wifi_quick_reconnect_active = false;
    if (!g_wifi_was_up) {
      Serial.printf("[wifi] link restored IP=%s RSSI=%d dBm\r\n",
                    WiFi.localIP().toString().c_str(), WiFi.RSSI());
      wifi_notify_link_up();
    }
    return;
  }

  if (g_wifi_was_up) {
    Serial.println("[wifi] link lost (poll)");
    wifi_notify_link_down();
  }

  if (g_wifi_quick_reconnect_active) {
    if (wifi_link_up()) {
      Serial.printf("[wifi] quick reconnect ok IP=%s RSSI=%d dBm\r\n",
                    WiFi.localIP().toString().c_str(), WiFi.RSSI());
      wifi_notify_link_up();
      return;
    }
    if (now - g_wifi_quick_reconnect_start_ms < kWifiQuickReconnectWaitMs) {
      return;
    }
    g_wifi_quick_reconnect_active = false;
  }

  if (!g_wifi_reconnect_pending && now - g_wifi_last_check_ms < kWifiCheckIntervalDownMs) {
    return;
  }
  g_wifi_last_check_ms = now;
  if (now - g_wifi_last_reconnect_ms < g_wifi_reconnect_backoff_ms) {
    return;
  }
  g_wifi_last_reconnect_ms = now;
  wifi_try_reconnect_now();
}

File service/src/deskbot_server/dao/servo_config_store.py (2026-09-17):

"""舵机调试配置持久化（``data/servo.json``）。"""

from __future__ import annotations

from typing import Any

from deskbot_server.constants import SERVO_CFG_FILE
from deskbot_server.dao._json_store import load_json_file, save_json_file
from deskbot_server.utils.device_data import resolve_json_path

DEFAULT_SERVO_LIMITS: dict[str, int] = {"xMin": 0, "xMax": 180, "yMin": 70, "yMax": 110, "xReverse": 0, "yReverse": 0}

DEFAULT_SERVO_PERSPECTIVE = "viewer"
_VALID_PERSPECTIVES = frozenset({"viewer", "robot"})

# 观众视角下 left/right 类预设 id 与本体存储 id 的对调（预设 steps 仍为本体逻辑坐标）
VIEWER_LR_SWAP: dict[str, str] = {
    "look_left": "look_right",
    "look_right": "look_left",
    "look_upper_left": "look_upper_right",
    "look_upper_right": "look_upper_left",
    "look_lower_left": "look_lower_right",
    "look_lower_right": "look_lower_left",
}


def normalize_perspective(raw: object) -> str:
    p = str(raw or DEFAULT_SERVO_PERSPECTIVE).strip().lower()
    return p if p in _VALID_PERSPECTIVES else DEFAULT_SERVO_PERSPECTIVE


def servo_perspective(*, device_id: str | None = None) -> str:
    """``servo.json`` 中的 left/right 语义：``viewer``（默认）或 ``robot``。"""
    try:
        cfg = load_servo_cfg_file(device_id=device_id)
    except (OSError, ValueError):
        cfg = None
    if cfg:
        return normalize_perspective(cfg.get("perspective"))
    return DEFAULT_SERVO_PERSPECTIVE


def resolve_move_for_perspective(move_id: str, *, device_id: str | None = None, perspective: str | None = None) -> str:
    """按视角解析 move/preset id（``viewer`` 时对调 left/right 类预设）。"""
    pid = str(move_id or "").strip()
    if not pid:
        return pid
    pers = normalize_perspective(perspective) if perspective is not None else servo_perspective(device_id=device_id)
    if pers != "viewer":
        return pid
    want = pid.lower()
    for src, dst in VIEWER_LR_SWAP.items():
        if src.lower() == want:
            return dst
    return pid


def _clamp_axis(v: int, lo: int, hi: int) -> int:
    a = min(int(lo), int(hi))
    b = max(int(lo), int(hi))
    return max(a, min(b, int(v)))


def _limits_with_reverse(limits: dict[str, int] | None = None, *, device_id: str | None = None) -> dict[str, int]:
    lim = dict(DEFAULT_SERVO_LIMITS)
    if limits:
        lim.update({k: int(limits[k]) for k in DEFAULT_SERVO_LIMITS if k in limits})
    else:
        lim.update(servo_limits(device_id=device_id))
    return lim


def logical_step_to_protocol(step: dict[str, Any], limits: dict[str, int]) -> dict[str, int]:
    """逻辑坐标 step → PB 协议坐标（与调试页 ``_servoStepToProtocol`` 一致）。"""
    xm = 1 if int(step.get("xm", 0)) == 1 else 0
    ym = 1 if int(step.get("ym", 0)) == 1 else 0
    lx = int(step.get("x", 0))
    ly = int(step.get("y", 0))
    ms = int(step.get("ms", 0))
    x_rev = int(limits.get("xReverse", 0)) == 1
    y_rev = int(limits.get("yReverse", 0)) == 1

    if xm == 0:
        clx = _clamp_axis(lx, limits["xMin"], limits["xMax"])
        x = (limits["xMin"] + limits["xMax"] - clx) if x_rev else clx
    else:
        dx = lx
        if x_rev:
            dx = -dx
        x = int(dx)

    if ym == 0:
        cly = _clamp_axis(ly, limits["yMin"], limits["yMax"])
        y = (limits["yMin"] + limits["yMax"] - cly) if y_rev else cly
    else:
        dy = ly
        if y_rev:
            dy = -dy
        y = int(dy)

    return {"xm": xm, "ym": ym, "x": x, "y": y, "ms": ms}


def servo_limits(*, device_id: str | None = None) -> dict[str, int]:
    """读取设备/全局 ``servo.json`` 限位；缺失字段回退 ``DEFAULT_SERVO_LIMITS``。"""
    out = dict(DEFAULT_SERVO_LIMITS)
    try:
        cfg = load_servo_cfg_file(device_id=device_id)
    except (OSError, ValueError):
        cfg = None
    if cfg:
        for key in out:
            if key in cfg:
                out[key] = int(cfg[key])
    return out


def clamp_servo_step(
    step: dict[str, Any], *, device_id: str | None = None, limits: dict[str, int] | None = None
) -> dict[str, int]:
    """逻辑 step → 协议 step（限位 clamp + xReverse/yReverse）。"""
    lim = _limits_with_reverse(limits, device_id=device_id)
    return logical_step_to_protocol(step, lim)


def normalize_servo_step(raw: object) -> dict[str, int]:
    if not isinstance(raw, dict):
        raise ValueError("preset step must be an object")
    out: dict[str, int] = {}
    for key in ("x", "y"):
        try:
            out[key] = max(-180, min(180, int(raw.get(key, 0))))
        except (TypeError, ValueError) as exc:
            raise ValueError(f"invalid step {key}") from exc
    for key in ("xm", "ym"):
        out[key] = 1 if int(raw.get(key, 0)) == 1 else 0
    try:
        out["ms"] = max(50, min(10000, int(raw.get("ms", 400))))
    except (TypeError, ValueError) as exc:
        raise ValueError("invalid step ms") from exc
    return out
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

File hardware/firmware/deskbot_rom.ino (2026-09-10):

// Deskbot — XIAO ESP32S3 Sense：摄像头 + pb + 音频 + 显示屏 + 舵机
#include <WiFi.h>
#include "display_panel.h"
#include "camera.h"
#include "camera_ws_transport.h"
#include "deskbot_config.h"
#include "wifi_provision.h"
#include "display.h"
#include "speaker.h"
#include "mic.h"
#include "pb_runtime.h"
#include "ws_transport.h"
#include "head.h"
#include "cmd.h"
#include "led.h"
#include "audio_frontend_esp_sr.h"
#include "logger.h"
#include "task_trace.h"
#include "utils/utils.h"
#include "utils/nvs_config_utils.h"
#include "boot_guide.h"

/* loopTask 只做 cmd / wifi maintain / yield；Opus encode 在 mic、decode 在 pb_runtime。
 * 覆盖弱符号 getArduinoLoopTaskStackSize（platformio.ini 另有 -DARDUINO_LOOP_STACK_SIZE）。 */
size_t getArduinoLoopTaskStackSize() {
  return 8 * 1024;
}

static void on_wifi_link_down() {
  ws_transport_on_link_down("wifi lost");
  camera_ws_transport_on_link_down();
}

static void on_wifi_link_up() {
  ws_transport_on_link_up();
  camera_ws_transport_on_link_up();
}

void setup() {
  Serial.begin(115200);
  Serial.flush();
  /* USB CDC 在 ESP32-S3 上 !Serial 永远为 false，用固定 delay 等待监视器连接。
   * 3s 足够 Linux/macOS 完成 USB CDC 枚举并让 flash_rom.sh 启动监视器。
   * 独立运行（无 USB）时同样只多等 3s，不影响正常功能。 */
  delay(3000);
  log_set_level(LOG_LEVEL_WARN);
  log_info("Initializing Deskbot...");
  log_info("[BOOT] device_id=%s", get_device_id());

  /* 上电立即归中：MCPWM 独立于 LEDC，不需要等 camera init。 */
  setup_head();

  /* ---- 阶段 A：先验证相机（RGB565），再释放 GDMA，避免 I2S/WiFi 期间卡死 ----
   * 本机 JPEG 硬件编码不可用；setup_camera 内用 RGB565 + frame2jpg。
   * ESP32-S3：相机 GDMA 在 WiFi STA 连接时若仍在跑，会整机挂死。 */
  static bool s_camera_ok = false;
  const bool camera_probed = setup_camera();
  if (camera_probed) {
    camera_deinit();
    log_warn("[CAMERA] suspended for i2s/wifi (will reinit after STA)");
  } else {
    log_warn("[BOOT] Camera absent or failed — continuing without camera");
  }

  setup_display();
  display_backlight_on();
  setup_FFat();
  setup_led();
  setup_mic();
  setup_speaker();
  /* ESP-SR AFE（AEC/NS/AGC/VAD）：失败不致命，mic 自动退回原始帧。 */
  audio_frontend_setup();

  log_info("[BOOT] device_id=%s version=%s", get_device_id(), VERSION);

  (void)wifi_provision_ap_offer(nvs_get_ap_offer_timeout_ms());
  if (!wifi_provision_connect_sta()) {
    wifi_provision_config_portal();
    if (!wifi_provision_connect_sta()) {
      log_error("WiFi connect failed");
      boot_guide_wifi_result(false, nullptr, "请重启或配网");
      return;
    }
  }
  wifi_provision_set_link_handlers(on_wifi_link_down, on_wifi_link_up);

  /* ---- 阶段 B：云服务器连接（屏幕引导）----
   * 先建 pb 帧队列，避免 WS ready 后下行帧因 pb 未 setup 被丢。
   * pb 任务必须在 display/head 队列就绪后再启动，否则 attention SLEEP 会对空 queue 断言。 */
  task_setup_speaker();
  /* mic 任务延后到相机重 init 之后再起，避免 GDMA 把 I2S0 PDM 冲掉。 */
  if (!setup_pb_runtime()) {
    log_error("[BOOT] pb_runtime setup failed");
  }
  if (!setup_ws_transport()) {
    log_error("[BOOT] ws_transport setup failed");
    boot_guide_server_result(false, "初始化失败");
    delay(1200);
  } else if (!task_setup_ws_transport()) {
    log_error("[BOOT] ws_transport task_setup failed");
    boot_guide_server_result(false, "任务启动失败");
    delay(1200);
  } else {
    (void)boot_guide_wait_ws_ready(DESKBOT_WS_CONNECT_TIMEOUT_MS);
  }

  /* WiFi 后再 init；舵机 MCPWM attach 须在相机之后。 */
  if (camera_probed) {
    s_camera_ok = setup_camera();
    if (!s_camera_ok) {
      log_warn("[BOOT] Camera reinit after WiFi failed");
    }
  }
  /* 无论相机成败：只要走过相机路径，PDM 都重挂一次更稳。 */
  if (!mic_restart_pdm()) {
    log_error("[BOOT] mic PDM restart failed");
  }
  task_setup_mic();

  /* ---- 阶段 C：执行器就绪后再启动 pb 泵 / camera 上行 ---- */
  /* 渲染任务停用在 task_setup_display 内部（TEMP-DISABLE），队列创建保留 */
  task_setup_display();
  task_setup_head();
  if (!task_setup_pb_runtime()) {
    log_error("[BOOT] pb_runtime task_setup failed");
  }

  if (s_camera_ok) {
    if (setup_camera_ws_transport() && task_setup_camera_ws_transport()) {
      task_setup_camera();
    } else {
      log_error("[BOOT] camera websocket startup failed");
    }
  } else {
    log_warn("[BOOT] Skipping camera uplink (no camera)");
  }

  log_info("[BOOT] firmware=%s %s %s", VERSION, __DATE__, __TIME__);
  char ws_url[128];
  deskbot_ws_format_active_url(ws_url, sizeof(ws_url));
  log_info("[BOOT] device_id=%s ws=%s version=%s", get_device_id(), ws_url, VERSION);
  log_info("PSRAM size=%u free=%u", (unsigned)ESP.getPsramSize(), (unsigned)ESP.getFreePsram());

  boot_guide_show_ready();
  log_info("%s is Ready. http://%s", PRODUCT_NAME, WiFi.localIP().toString().c_str());
  log_warn("[BOOT] ready device=%s ws=%s wifi_ip=%s",
           get_device_id(), ws_url, WiFi.localIP().toString().c_str());
  log_set_level(LOG_LEVEL_WARN);
}

void loop() {
  handle_cmd();
  wifi_provision_maintain();
  log_task_tick();
  yield();
}

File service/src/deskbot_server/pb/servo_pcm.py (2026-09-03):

"""舵机交错、PCM 对齐与 pb JSON wire 消息。"""

from __future__ import annotations

import copy
import logging
import os
import random
from collections import deque
from typing import Any

from deskbot_server.constants import pb_max_chunk_ms_for_pcm
from deskbot_server.pb.shapes import (
    PB_ACTION_REPLACE,
    PB_LEVEL_TASK,
    attach_pb_device_hints,
    normalize_anim_list_for_wire,
)

logger = logging.getLogger("deskbot-server")

# 分片合并：单片时长上限默认 500ms；仍受 ESP32 WS BINARY 单帧上限约束（约 10s@16kHz，统一下发采样率）
_PB_CHUNK_MS_USER = max(100, int(os.environ.get("PB_CHUNK_MS_MAX", "500")))
PB_CHUNK_MS_MAX = min(_PB_CHUNK_MS_USER, pb_max_chunk_ms_for_pcm(16000))
if PB_CHUNK_MS_MAX < _PB_CHUNK_MS_USER:
    logger.info(
        "[pb] PB_CHUNK_MS_MAX 由 %d 收紧为 %d（ESP32 PCM 单帧上限，约 %d 字节）",
        _PB_CHUNK_MS_USER,
        PB_CHUNK_MS_MAX,
        (PB_CHUNK_MS_MAX * 16000 // 1000) * 2,
    )


def make_anim_item(elements: dict[str, Any], ms: int, *, phoneme: str | None = None) -> dict[str, Any]:
    """构造 ``anim[]`` 单项：``{ elements, ms, phoneme? }``。"""
    item: dict[str, Any] = {"elements": copy.deepcopy(elements), "ms": max(1, int(ms))}
    ph = str(phoneme or "").strip()
    if ph:
        item["phoneme"] = ph
    return item


def anim_elements_from_row(row: dict[str, Any]) -> dict[str, Any]:
    """从 anim 行读取 ``elements``（兼容旧 ``anim: {elements}``）。"""
    anim = row.get("anim")
    if isinstance(anim, list):
        for one in anim:
            if isinstance(one, dict) and isinstance(one.get("elements"), dict):
                return one["elements"]
    if isinstance(anim, dict) and isinstance(anim.get("elements"), dict):
        return anim["elements"]
    return {}


def normalize_row_anim_list(row: dict[str, Any]) -> list[dict[str, Any]]:
    """保证 ``row['anim']`` 为 ``[{elements, ms, phoneme?}, ...]``。"""
    anim = row.get("anim")
    chunk_ms = max(1, int(row.get("chunk_ms") or 0))
    if isinstance(anim, list):
        out: list[dict[str, Any]] = []
        for one in anim:
            if not isinstance(one, dict):
                continue
            els = one.get("elements")
            if not isinstance(els, dict):
                continue
            ms = max(1, int(one.get("ms") or chunk_ms))
            out.append(make_anim_item(els, ms, phoneme=one.get("phoneme")))
        if out:
            return out
    if isinstance(anim, dict) and isinstance(anim.get("elements"), dict):
        ph = str(row.get("phoneme") or "").strip() or None
        return [make_anim_item(anim["elements"], chunk_ms, phoneme=ph)]
    return []


def merge_pb_subchunks(
    rows: list[dict[str, Any]], pcm_list: list[bytes], *, sample_rate: int, max_chunk_ms: int = PB_CHUNK_MS_MAX
) -> tuple[list[dict[str, Any]], list[bytes]]:
    """将细粒度分片合并为 ``chunk_ms <= max_chunk_ms`` 的 pb 行。

    块边界对齐到 20ms opus 帧：合并时块尾不足一帧的 PCM **预借给下一块**开头
    （``carry``），保证每块 PCM 都是整帧长度 → 下行 opus 编码零补零、块间无静音
    插入、时间轴零漂移。末块不切尾（流结束无承接者，避免丢尾巴）。
    """
    if not rows:
        return [], []

    merged_rows: list[dict[str, Any]] = []
    merged_pcm: list[bytes] = []
    batch_anim: list[dict[str, Any]] = []
    batch_servos: list[dict[str, Any]] = []
    batch_pcm = b""
    batch_ms = 0
    carry_pcm = b""
    carry_ms = 0

    def _prepend_carry(pcm: bytes, ms: int, anim_items: list[dict[str, Any]]) -> tuple[bytes, int, list[dict[str, Any]]]:
        """把上一块切下的帧余量并入当前行（PCM 头 + 时长 + 首条 anim）。"""
        nonlocal carry_pcm, carry_ms
        if not carry_ms:
            return pcm, ms, anim_items
        merged = carry_pcm + pcm
        total_ms = carry_ms + ms
        if anim_items:
            anim_items = [
                {**anim_items[0], "ms": int(anim_items[0].get("ms") or 0) + carry_ms},
                *anim_items[1:],
            ]
        carry_pcm, carry_ms = b"", 0
        return merged, total_ms, anim_items

    def _flush(*, final: bool = False) -> None:
        nonlocal batch_anim, batch_servos, batch_pcm, batch_ms, carry_pcm, carry_ms
        if not batch_anim:
            batch_servos = []
            batch_pcm = b""
            batch_ms = 0
            return
        if not final:
            # 帧对齐：块尾不足 20ms 的部分切给下一块，避免 opus 编码补零产生块间静音
            excess = batch_ms % 20
            if excess and batch_pcm:
                tail_bytes = excess * sample_rate * 2 // 1000
                if 0 < tail_bytes < len(batch_pcm):
                    carry_pcm = batch_pcm[-tail_bytes:]
                    carry_ms = excess
                    batch_pcm = batch_pcm[:-tail_bytes]
                    if batch_anim:
                        last = batch_anim[-1]
                        last["ms"] = max(1, int(last.get("ms") or 0) - excess)
                    batch_ms -= excess
                else:
                    carry_pcm, carry_ms = b"", 0
        else:
            carry_pcm, carry_ms = b"", 0
        row: dict[str, Any] = {"chunk_ms": batch_ms, "anim": batch_anim}
        if batch_servos:
            row["servo"] = batch_servos
        merged_rows.append(row)
        merged_pcm.append(batch_pcm)
        batch_anim = []
        batch_servos = []
        batch_pcm = b""
        batch_ms = 0

    for i, row in enumerate(rows):
        row_ms = max(1, int(row.get("chunk_ms") or 0))
        anim_items = normalize_row_anim_list(row)
        if not anim_items:
            anim_items = [make_anim_item({}, row_ms)]
        pcm = pcm_list[i] if i < len(pcm_list) else b""
        servos = row.get("servo")
        servo_items: list[dict[str, Any]] = []
        if isinstance(servos, list):
            for cmd in servos:
                if isinstance(cmd, dict) and "xm" in cmd and "ym" in cmd:
                    servo_items.append(
                        {
                            "xm": int(cmd["xm"]),
                            "ym": int(cmd["ym"]),
                            "x": int(cmd["x"]),
                            "y": int(cmd["y"]),
                            "ms": int(cmd["ms"]),
                        }
                    )
        elif isinstance(servos, dict) and "xm" in servos and "ym" in servos:
            servo_items.append(
                {
                    "xm": int(servos["xm"]),
                    "ym": int(servos["ym"]),
                    "x": int(servos["x"]),
                    "y": int(servos["y"]),
                    "ms": int(servos["ms"]),
                }
            )

        if row_ms > max_chunk_ms:
            _flush()
            pcm2, ms2, anim2 = _prepend_carry(pcm, row_ms, anim_items)
            one_row: dict[str, Any] = {"chunk_ms": ms2, "anim": anim2}
            if servo_items:
                one_row["servo"] = servo_items
            merged_rows.append(one_row)
            merged_pcm.append(pcm2)
            continue

        if batch_ms and batch_ms + row_ms > max_chunk_ms:
            _flush()
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

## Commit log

2026-08-28 transfer from v1
    [BOM_Board1_PCB1_2026-06-12.xlsx, Board1.kicad_pcb, Board1.kicad_sch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]
2026-08-29 pb 流控：服务端末窗口等 pb_end，固件 pb_cancel 直接通知抢占
    服务端（device_ws_service.py）：_wait_ack 区分 ack_type，末窗口必须收到
    pb_end 才结束 seq 并允许下发下一 seq，修复同 req 链被提前放行导致的重复播放。
    新增 tests/test_pb_ack_window.py 六个用例。
    固件（pb_runtime.cpp）：入队即解析为 pb_model（队列直接存模型，出队零二次
    解析）；pb_cancel 不走模型队列，清空旧链积压模型并直接通知任务，drain/space
    等待被打断，执行器立即 abort，被抢占链不发 ack。
    deskbot_rom.ino：日志级别保持 INFO，便于观察 pb ack 时序。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
    [deskbot_rom.ino]
2026-08-29 固件 pb_cancel 抢占重构：cancel 入队 + 标志 + 任务侧 drain
    - cancel 帧解析后正常入队（模型队列），入队前在锁内置 s_pending_cancel
    标志（与入队原子），不再跨任务清队列、不再走 req 拷贝通知通道。
    - 新增 handle_pb_cancel()：标志置位则出队丢弃 cancel 及其之前的旧链积压帧
    （cancel 之后的新链帧保留），abortRound 清执行器（放锁后调用，执行器
    abort 是阻塞入队）。
    - 任务主循环开头与 drain/space 等待循环均调用 handle_pb_cancel()，抢占
    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
2026-08-29 固件音频全双工：AEC 集成 + 移除 speaker/mic 半双工互斥
    - 接入 ESP-SR AFE（AEC/NS/AGC/VAD）MR 全双工管线（audio_frontend_esp_sr）
    - 移除 speaker/mic 不同时打开的门控：MicSpeakerState 状态机、可听阈值挡麦、尾音抑制、空闲强制放麦全部删除，上行只受 ws 状态约束
    - SAMPLE_RATE 从 speaker.h 迁到 deskbot_config.h，mic 不再传递依赖 speaker.h
    - esp_sr_fetch 任务挪至 PRO_CPU + prio6：修复播放期 APP_CPU 繁忙导致 AEC 处理被饿死、上行走 raw fallback（回声 5x 上行）的问题
    - 清理 audio_frontend 死代码：3 个零调用公共 API、flush generation 机制、心跳打点、feed 路径每帧 2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
    [deskbot_config.h, deskbot_rom.ino, mic.cpp]
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2026-08-29 debug: 诊断 WS 断连——记录 WiFi 断开原因与相机上行状态
    - wifi: 记录 STA 断开原因码 g_wifi_last_disconnect_reason，事件日志带 reason
    - camera: 上行暂停/恢复状态日志（ws down/up）；帧诊断加 free_int/free_total/RSSI
    - ws_transport: 相机帧发送成功日志（len + send_ms），定位 sendBIN fail 周期
    [wifi_maintain.cpp]
2026-08-29 docs: README 全面重写 + 全仓文档对齐当前代码；依赖与舵机配置调整
    - 根 README 重写：拟人化开场突出亮点，补快速安装/使用手册/技术速览
    - 全仓 md 对齐代码现状：设备 WS 仅 device_id 鉴权（去 pin_code/API Key）、
    火山方舟 LLM（去 DashScope）、全双工 AEC（去半双工表述）、
    数据目录 data/{device_id}/（去 PIN 隔离）、删除 paddlespeech 侧车与
    不存在的 API 路由/模块引用
    - service 依赖调整（移除 webrtcvad，aiohttp 等移入 miot extra）、
    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
    [servo.json]
2026-08-29 feat: 默认音素时长转换函数——文本+音频总时长 → 音素时间轴，供无音素 TTS 补充口型
    utils/phoneme_duration: 中文拼音拆声母/韵母 + 英文 G2P 映射口型键，
    按单元权重比例分配 total_ms（总和守恒），输出兼容豆包 phonemes 格式。
    附单元测试 7 例。
2026-08-30 feat: 剧本任务系统 + 外部服务管理 + ASR 重构 + 机器人设置
    剧本任务系统（剧情设计）：
    - quest_service 任务引擎：剧本 JSON 定义（校验/环检测）、状态机（not_started→running→success/failed）、
    分数流转（on_success/on_failure 传播+达标自动激活）、任务改名联动引用与实例、title 默认值
    - 工具函数：update_task_result / update_task_strategy / contribute_score / set_state（沙箱）
    - 设备视角查询：get_current_tasks / get_tool_calls（运行时接线预留）
    - 剧情设计后台：模块连线编辑器（缩放/平移/节点原地编辑/撤销/导入导出/沙箱模拟）
    - 路由挂载 + 侧边栏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
    [config.yaml]
2026-08-30 feat: ASR 协议 v1 落地 + 豆包接入 + funasr 完全独立化
    ASR 外部服务协议 v1（docs/asr_protocol.md）：
    - infrastructure/asr/protocol.py：请求归一化（PCM+X-Sample-Rate / WAV 自描述）、
    统一错误结构 {"error": {code, message}}、客户端响应校验与错误提取
    - utils/asr_segments.py：句子级时间戳补全（按标点切句 + 字符等分 + 末段吃余量，
    与 phoneme_duration 解耦）
    - externals/funasr 服务协议化：支持 WAV 输入、标准错误码、响应带 elapsed_ms
    - ASR HTTP 适配器（http_adapter → funasr_adapter）响应解析走协议层，错误携带 code
    豆包（火山一句话识别 v1）接入：
    - infrastructur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
    [config.yaml]
2026-08-30 feat: TTS 引擎迁移 moss-tts-nano + insightface 引擎完善 + 端口统一 5050→9000
    - TTS: tts-engine 迁移为 moss-tts-nano（install/patch/service.yaml 随迁），新增 moss_adapter，工厂接入
    - insightface: 引擎补 install.sh 与共享 deskbot_server 模块（人脸检测/身份/去畸变），config/server/service 更新
    - 机器人设置/外部服务管理: contract/manager/settings/robot_capability/camera_face_service/phoneme_duration 更新，机器人设置页扩展
    - 端口: Web 控制台默认并入主服务 :9000，代码与全部文档 5050→9000 统一（独立进程 DESKBOT_START_WEB=1 时可另起）
    - 测试: 新增 test_tts_external，外部服务/机器人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
2026-08-30 feat: 机器人设置 TTS 音色选择与试听 + 人脸识别能力开关 + 豆包 ASR 凭证管理
    - TTS 默认 moss-tts-nano 独立进程（externals/moss-tts-nano 目录与 manifest 对齐），MossTtsAdapter（/api/generate → WAV → mono → phoneme_duration 补音素，48k）
    - 机器人设置页 TTS 候选选择 + 音色设置（moss demo-N / 豆包预设 36 个，data/doubao_tts_speakers.json）+ 候选行测试按钮 + 试听播放器；apply_tts/tts_test 统一 voice_id 语义（moss→tts.demo_id，doubao→tts.doubao_speaker 优先于 .env）
    - 人脸识别能力开关（camera_face.mode: none/insightface），移除 internal 人脸实现
    - 豆包 ASR 凭证 env 管理（infra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
2026-08-30 feat: ASR 配置/测试对话框 + 音频试听播放器 + 修复人脸卡片空白
    - ASR 候选行「配置」按钮：funasr 测试（默认音频 data/test/asr.wav + 本地文件选择，展示 HTTP 码/耗时/文本）；豆包配置表单（DOUBAO_ASR_* 六字段，掩码/空值不覆盖已有）+ 同款测试（表单值覆盖 env，免保存即测）
    - 默认音频播放端点 GET /api/robot-settings/asr/default-audio；对话框音频播放器双源：默认音频端点 ↔ 用户文件 blob object URL（关闭时 revoke）
    - audio_norm（WAV/raw PCM → 16k 单声道归一化）与 asr/env_store（.env 读写映射）收尾修复
    - 修复机器人设置页空白：人脸卡片缺 fa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
2026-08-30 feat: 管理后台顶栏设备绑定交互——下拉切换 + 管理删除 + 绑定新设备
    - 顶栏 LINK·OK 位置改为设备下拉选择器：设备 ID / 在线状态 / 最近访问时间，点击即切换当前设备
    - 右侧新增「管理」按钮：弹出设备表格（设备 ID / 是否在线 / 最近同步时间 / 删除解绑）
    - 管理旁新增「绑定新设备」：设备在线且未被其他账号绑定时绑定成功，否则提示错误
    - 修复 fetch_live_device_details 同进程读取 last_seen 字段错误（注册表为 last_seen_ts 时间戳）
    - /app/api/devices 返回 last_sync（最近同步时间，来自 last_pb_ack_ts）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
2026-08-31 feat: 后台 UI 迭代——favicon、顶栏设备操作按钮紧贴选择器、开发者选项分组
    - favicon：新增「歪」字 SVG 图标，统一接入 base_2c/auth_base/base 三套模板
    - 顶栏：「管理 / 绑定新设备」从右对齐位置移到设备选择器紧邻右侧
    - 侧栏：新增「开发者选项」分组（用户管理/独立服务管理），仅开发者可见
    - 新增 2C 风格用户管理页 /dev/users（RequireDeveloper）；独立服务管理页面与
    全部 API 升级为开发者鉴权（非开发者 403/307）
    - robot_settings 对普通用户隐藏独立服务管理链接
    - 修复 /api/services 登录保护前缀盲区；新增用户/服务管理 API 权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
2026-08-31 perf: 显示 SPI 频率 40→80MHz，推屏耗时减半
    ST7789 整帧推屏(284×240×2=136KB)经 40MHz SPI 实测 73-158ms/帧，
    80MHz 后推屏耗时约减半，动画帧率与渲染循环让出频率同步提升。
2026-08-31 refactor: 精简 LLM 调用链——删 LlmService 单例、合并工具循环与提示词模块
    - 删 service/llm_service.py：纯转发单例 + ChatService try/except 双通道死代码
    - llm_tool_loop 并入 chat_flow：5 元组返回改 LlmTurnResult dataclass，删冗余 on_tts_ready 回调与未引用的 is_llm_tool_call
    - user_message/face_scene/stream_tts 并入 utils/runtime：删 130 行死代码，infrastructure/llm 6 模块缩到 4 个
    - system prompt 组装抽为 build_llm_system_prompt()，openai_compat 与 debug_bp 共用，去重时间注入
    - 调用链 6 层变 4 层；全量测试基线对比零回归
2026-08-31 fix: 下行 opus 编码器跨 chunk 复用 + pb 分块 20ms 帧对齐，消除块边界断续/咔哒（固件日志 WARN + display 防御保护）
    [deskbot_rom.ino, logger.cpp, servo_pcm.py]
2026-08-31 feat: 实验台历史对话（调试记录）+ 鉴权简化
    - device_turn 表：每设备 record_history 开关（默认关），落库轮次时序/工具/模型名/system prompt 快照，音频图像存 data/device/{device_id}/
    - 用户语音/机器人 TTS/人脸帧落盘 hook；turn_recorder 组装写入
    - /api/device_turns + /media 接口（归属校验 + 路径白名单）
    - 实验台「历史对话」tab：会话列表 + 气泡（思考时长/ASR 解析/时长精确到毫秒）
    - WEB_SECRET_KEY 自动生成（data/global/web_secret_key，0600），不再回落硬编码
    - 移除 proxy 转发层：页面直连后端（cookie 会话），scene_playbooks 等 debug 接口随之可用
    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
2026-08-31 feat: 本地 MiniCPM5-1B（llm-minicpm）接入机器人设置，移除 llm-engine
    - 新增 llm-minicpm 外部服务：llama-server + MiniCPM5-1B-Q4_K_M.gguf（9105，OpenAI 兼容，Metal 加速；-rea off 关 think 实测提速 2.4x），install.sh 幂等（GitHub→gh-proxy / hf-mirror 回退 + GGUF 魔数校验）
    - 机器人设置「大脑 LLM」新增 minicpm 候选（requires_service=llm-minicpm + 实验性标注），前端数据驱动零改动；apply_llm 快照 ark 配置切回恢复；get_status 按 base_url 精确匹配
    - 移除 llm-engine（Cactus Needle 2）：外部服务目录、local 候选、LLM_ENGINE_* 常量及测试
    - .gitignore 增加 externals/*/bin/（llama-server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
2026-09-01 feat: llm-qwen 本地接入 + TTS 配置重构与机器人设置完善
    - 新增 externals/llm-qwen（Qwen3.8-2B + llama-server b10733，端口 9106），config.yaml LLM 切至本地 openai 协议
    - TTS 重构：新增 resolve.py 统一 provider 解析，移除 voice_clone 与 settings_test_limit/turn_recorder/device_turn_mapper
    - 新增 landing 落地页，调整 app2c 页面结构与鉴权简化
    - 机器人设置：LLM/TTS 配置热切换（config.yaml 真源 + rebind），新增相应测试
    - 剧本任务系统工具契约测试补充；data/*_tts/ 测试设备运行时数据入 .gitignore
    [config.yaml, web_controller.py]
2026-09-02 docs: 同步硬件 v2.0（PCB/BOM/3D打印）与本地模型优先表述
    - 新增 PCB V2.0 双板（主控 Base + 屏幕 LCM）渲染图、购买材料清单、
    新装配说明书/STEP/Gerber/BOM 链接至根 README 与 hardware README
    - 接线表更新为 v2 主控板 GPIO（LCD 5/4/6/7、舵机 16/15、NS4168 40/41/42、PDM 1/2）
    - docs/hardware-spec.md 清除 Board1 引用，同步 OV3660/NS4168/3.7g 舵机
    - 技术速览改为免费本地模型优先（Qwen3.8-2B/MiniCPM5-1B、MOSS-TTS-Nano），云端可配
    - 移除 start.sh 云 Key 必填检测与警告，.env.example 标记为可选
    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
    [BOM_Board1_PCB1_2026-06-12.xlsx, BOM_V2.0_Base_PCB_V2.0_Base_2026-09-02.xlsx, BOM_V2.0_LCM_PCB_V2.0_LCM_2026-09-02.xlsx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]
2026-09-02 fix: TTS 下发统一 16k 采样率，移除片间固定 150ms 间隙
    - moss 引擎 48k WAV 服务端降采样到 settings.tts.sample_rate（默认 16k，
    与豆包 DOUBAO_TTS_SAMPLE_RATE 一致）：设备端 opus 解码突发远小于
    I2S DMA 环覆盖，消除块边界断音（24k/48k 处于解码预算边缘带会偶发断点）
    - 新增 numpy windowed-sinc 抗混叠降采样工具 utils/audio_resample.py，
    moss/doubao adapter 均先归一化到统一采样率再切分口型
    - PB_CHUNK_GAP_MS 默认 150ms→0：节奏由 pb_ack 窗口流控（PB_WAIT_ACK +
    固件 executor space 门控）接管；固定间隙在 chunk 音频时长小于间隙时
    会饿死设备（供给 < 实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
    [config.yaml]
2026-09-02 chore: 日志治理——文件轮转 + 高频刷屏点降级 debug
    - logging_setup 改用 RotatingFileHandler（默认 100MB × 3 备份，
    DESKBOT_LOG_MAX_BYTES / DESKBOT_LOG_BACKUP_COUNT 可调）；
    实测 pb 帧序等高频 INFO 一天可达 GB 级
    - [pb TX] 帧序一览（每 chunk 整段 JSON）、[_enqueue] 队列决策、
    [live] delivered 摘要降为 debug（需要时 DESKBOT_SERVER_LOG_LEVEL=DEBUG）
2026-09-02 fix: pb 音频双重释放崩溃（speaker 队列满时入队失败路径）
    speaker_submit_pb_audio_owned 为 owned 语义：入队失败时已在函数内
    释放 audio 并返回 false，而 task_loop_pb_runtime 的失败分支未置空
    incoming.audio，随后 pb_model_free 二次释放同一指针 → PSRAM 堆头
    被 free list 元数据覆盖 → CORRUPT HEAP 断言重启（multi_heap_free）。
    崩溃在 moss/豆包 TTS 抢占或突发下发把 speaker 执行器队列顶满时触发；
    回退栈 0x4203e580→pb_model_free→pb_audio_free 已证实。现在失败路径
    统一置空指针，队列满时退化为丢一帧音频（WARN），不再崩溃。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
2026-09-02 feat: 本地引擎上下文预算裁剪 + 超限 400 半量裁剪重试
    本地 llama-server 的 n_ctx 被模型 n_ctx_train 钉死在 8192（-c 再大
    也会被 clamp），请求超限即 400 exceed_context_size_error。两段兜底：
    1) 请求前按 CJK≈1.1 token/字（其余 3.2 字符/token）估算，预留输出与
    JSON 重试轮的 token 空间，超预算从最旧开始裁剪历史（至少留最近一条）；
    2) 仍超限时砍掉最旧一半历史重建请求重试（≤3 次），JSON 重试提示词
    走 tail 追加不参与历史裁剪。service.yaml 同步注明 -c 8192 约束。
2026-09-02 chore: uv.lock 与 pyproject 同步（清理已移除的依赖）
    同步早前 pyproject 依赖裁剪后滞后的锁文件：移除 aliyun-python-sdk
    （core/kms）、antlr4-python3-runtime、audioop-lts 等已不再使用的包及
    其传递依赖。uv lock --check 通过（86 包）。
2026-09-02 docs: 硬件规格 v2——SPI/舵机/音频按 PCB V2.0 实际 GPIO 修正
    - SPI（屏）：按 v2 板丝印 GPIO 更新（MOSI 5/SCK 4/CS 6/DC 7），废弃
    XIAO Pad 映射列
    - 舵机 GPIO 更新为 16/15，标注 v2 主控板为准
    - 音频：明确 16kHz 统一下发（moss 48k 服务端降采样、豆包直连 16k），
    DMA 缓冲按 ESP_I2S 驱动实际 6×240 帧描述，XIAO Pad 映射降级为历史参考
2026-09-02 fix: AFE 路径去掉叠加的 5x 增益（enhance_voice 仅 raw 兜底生效）
    机器人开口时 AEC 残留被双重放大（afe_linear_gain ×5 + enhance_voice ×5，
    合计 25x），残留绝对电平抬 ~14dB，易越过服务器 Silero 切句阈值，把自家
    TTS 开头（如“好的”）幻听成用户发言（“好招”）并触发一轮假对话。
    AFE 输出已含 afe_linear_gain(5x)，legacy 5x+HPF 只在 raw fallback 路径
    保留，两条路径总增益维持 5x，收音响度不变。
    [mic.cpp]
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2026-09-02 fix: 开发者选项菜单页面与 API 仅限开发者身份访问
    「开发者选项」下的菜单此前只做导航隐藏（nav_is_developer），页面与配套
    API 仅 RequireUser，普通用户直连 URL 即可进入/调用。本次补齐服务端门禁：
    - /expr（表情设计）、/quest（剧情设计）页面及全部写 API 换 RequireDeveloper：
    quest 全部 /api/quest/*、POST emotion_expr_map / face_expr_scenes、
    GET+POST face_mouth_by_phoneme、scene_playbook/export_plan、
    face_design/generate-from-image、face_design/generate
    - 保留消费端首页 3D 预览所需 GET /api/face_expr_scenes、/api/emotion_expr_map
    - /api/face_design/generate 移出 debug_bp 消费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
2026-09-03 fix: 家页 TTS 说话口型改按音素口型表逐行播放
    下发 TTS 后首页表情模拟原先用正弦开口椭圆占位(mouth 图层兜底色呈橙红细线),与音素无关。现在 /api/device_tts 提交时带 want_sim,服务端用与设备 pb 同源的 text_to_phoneme_durations + phoneme_seq_to_anim_seq 估算逐音素表情行(talk_sim),前端按行时间轴播放 deskbot-face.json 里 a/i/u/o 等真实音素嘴型;接口不可用时回退旧口型。
    [web_controller.py]
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2026-09-03 feat: 社交主动问答（用户社交库落库/主动提问触发）+ LLM 工具链重构 + 依赖修复
    - service/application/social_proactive.py + dao/user_social_store.py：用户社交信息存储与主动提问调度，配套 4 个测试
    - llm infrastructure：utils/runtime/tool_schema/openai_compat 上下文与工具调用链重构（含原生工具 a0 测试）
    - live_service 主动交互、camera_face_service/采集流程调整；固件 camera/pb_model 同步清理
    - 删除 pb/cam_signal.py，改走现有下发链路
    - 补声明 Werkzeug==3.1.8（user_service 密码哈希依赖缺失，新机 setup 必崩）并刷新 uv.lock（顺带清除推理依赖迁出前残留）
    Co-Authored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
    [config.yaml, pb_model.cpp, servo_pcm.py]
2026-09-03 fix: 补声明 Jinja2==3.1.6（Web 控制台模板渲染硬依赖，新机 setup 必崩）
    web/mount.py 顶层 import fastapi.templating.Jinja2Templates，jinja2 属必装；
    开发机 .venv 为手动装入、未声明，新机器缺失即 ModuleNotFoundError。
    同步 requirements.txt / pyproject.toml，uv.lock 重新生成。
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2026-09-04 fix: llm-minicpm/llm-qwen 二进制按平台自动下载（Linux 不再误装 macos-arm64 报 Exec format error）
    - install.sh uname 探测平台：macOS arm64/x64 → macos-*，Linux x86_64/aarch64 → ubuntu-*（llama.cpp 官方 Linux 资产沿用 ubuntu 前缀，同为 tar.gz）
    - bin/ 写 .platform 标记：跨平台拷贝（macOS→Linux）重跑安装会清空重下，--version 校验通过才落标记
    - 模型大小校验 stat -f %z（BSD 专属）改 wc -c，修 Linux GNU stat 恒判失败
    - manager.py spawn ENOEXEC 专属提示「先卸载再重装」；service.yaml/候选文案/文档去除 Metal 硬编码
2026-09-04 fix: asr_chat 连接接管防卡死——先换后清 + generation 门控 + 全程有界等待
    09-04 早 08:54 同设备 3ms 双连触发接管竞态：register() 在旧连接清理的无超时
    await 上永久卡死，此后每条新连接都服务不了（只打「关闭旧连接」、再无
    接入/ready），设备永远收不到 ready → ~14.6s 重连风暴且不自愈，重启才恢复。
    - register 先换 entry.ws 并递增 generation，同步摘除旧 seq/dl worker 后立起
    新代 worker：新连接服务绝不依赖旧连接清理完成
    - worker/下行 job 按代数门控：旧代任务不得向新连接发帧、退出不回写共享状态
    - 旧连接 close 有界（_SUPERSEDE_CL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
2026-09-04 fix: 相机 TV/实验台 WS 基址跟随访问 Host——0.0.0.0 部署不再硬连 127.0.0.1
    home(相机 TV)/lab(实验台实时对话)模板注入 camera_view/device_pipeline
    WS 基址时未传 request，config host=0.0.0.0 被过滤后兜底成 127.0.0.1；
    局域网 IP 打开页面时 WS 连到浏览器本机，握手失败且服务端无任何日志。
    三处渲染点(app2c home/lab、debug devices)改为传 request；home/lab 前端
    补与调试台同款 alignWsBaseToPageHost 运行时对齐页面 host 作双保险。
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2026-09-10 feat: 剧本任务系统重构——去分数三态状态机 + complete_task 统一工具 + 日常/长期任务永续
    任务模型：
    - 删除分数机制：quest_instance.current_score/strategy_override 两列移除，
    contribute_score 与带分数的连线（端口+分值）一并删除，连线改为「后继单端口」
    set_edge(from, to)
    - 状态机收敛为 not_started → running → completed（仅一次性任务到终态），
    旧库 success/failed 归一为 completed；init_db 新增重建表迁移（幂等，
    同 scheduled_tasks 先例），定义字段改为 type/prompt/next_task_ids
    - 任务分三类 once/daily/long_term（TYPE_LABELS）：一次性完成后自动激活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
2026-09-10 fix: 配网页「继续启动」不再误报 failed to fetch——响应送达后再关热点，断连按正常处理
    设备收到指令后主循环立刻 wifi_portal_stop()（close + WIFI_OFF 关热点），HTTP
    响应常还堵在发送缓冲里就被掐断，浏览器只看到 failed to fetch——用户无从判断
    到底有没有启动成功。
    - 后端：continue-boot 处理函数在 send_ok() 后 delay(300)，让 lwIP 先把响应发出去
    并等到 ACK，多数情况下页面能正常收到 success:true，不再走容错分支。
    - 页面：即便仍然断连也不报错，转为「已继续启动」绿色提示（原成功路径本无任何
    反馈，用户同样不知道是否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
2026-09-11 fix: PB 下发 ACK 超时保护——避免 ACK 丢失把设备 worker 永久卡死
    服务端靠 PB_WAIT_ACK 逐窗口等待设备 pb_ack 流控，但等待无上限：设备侧执行器
    状态损坏、ACK 帧在队列/链路中丢失，或末窗口等不到 pb_end 时，设备 worker 会永久
    停在 ack_queue.get()，该设备此后再无任何下发——只能重启服务恢复。固件侧同样有
    两处死等（等执行器腾空间、等执行器播毕），任一卡住则 PB 泵彻底失活，连 cancel
    都无人消费。
    服务端（device_ws_service）：
    - _wait_ack 增加 deadline：窗口 ACK 默认 PB_ACK_WINDOW_TIMEOUT_SEC=3s，
    末窗口覆盖 PB 声明总时长 + grace（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
2026-09-11 feat: say 过渡语工具——工具轮「边干活边说」+ 三层降级兜底
    模型调慢工具（搜索、注册、看画面）时用户要干等几秒到十几秒，全程无声。旧版只在
    工具轮结束后才用词表拼一句「稍等，我帮你搜一下。」——说的时候搜索已经做完了，
    既没填上等待，又因为词表覆盖了记忆落库、会话切换等本地毫秒级工具，给「刚刚发生」
    的事补一句「稍等，我记下了」，听起来啰嗦且错位。
    改为模型自述优先 + 边干活边说，过渡语三层降级（resolve_interim_tts）：
    1. 模型调 say 工具说的一句（首选）；say 与真工具同时调用时立即回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
2026-09-14 feat: 交互仲裁 + 活物感修复 + 重复提问抑制 + 场景 playbook 瘦身
    汇总本轮工作树上的多条并行改动。
    **1. 交互仲裁（新增 interaction_arbiter.py）**
    按设备对「会产生语音的交互轮」做确定性仲裁，不掺对话语义：用户轮优先级最高、可
    取消在途系统轮；定时提醒进每设备队列排队；主动问候/剧情推进 best-effort，忙时直接
    丢弃；同设备普通轮不并发。租约覆盖 LLM → TTS → PB 整个生命周期，因此「忙」在 LLM
    调用前就生效，而不是等播放阶段才占位。
    配套在 ChatTurnResult 上回传播放终态（playback_completed / playback_status /
    playback_reason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
    [servo.json]
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2026-09-17 feat: 大脑 LLM 默认接入硅基流动云端 + 修复 Qwen/ 前缀被剥 + 系统默认可携带密钥
    「机器人配置 → 大脑 LLM」新增云端 provider `siliconflow`（硅基流动），并把它设为
    系统默认。本地 1B/2B 模型工具调用弱、话术呆，ark 要钱且需每设备手填 key；硅基流动
    目前免费提供 Qwen/Qwen3-8B，OpenAI 兼容、国内线路好（实测 TLS 30–40ms）。
    **1. 系统默认切到硅基流动，且不需要 DB 迁移**
    config.yaml llm 段改为 protocol=openai / api.siliconflow.cn/v1 / Qwen/Qwen3-8B /
    api_key_env=SILICONFLOW_API_KEY / context_window=32768。
    新设备的 llm_provider 列本来就是空串（device_mapper 的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
    [config.yaml]
